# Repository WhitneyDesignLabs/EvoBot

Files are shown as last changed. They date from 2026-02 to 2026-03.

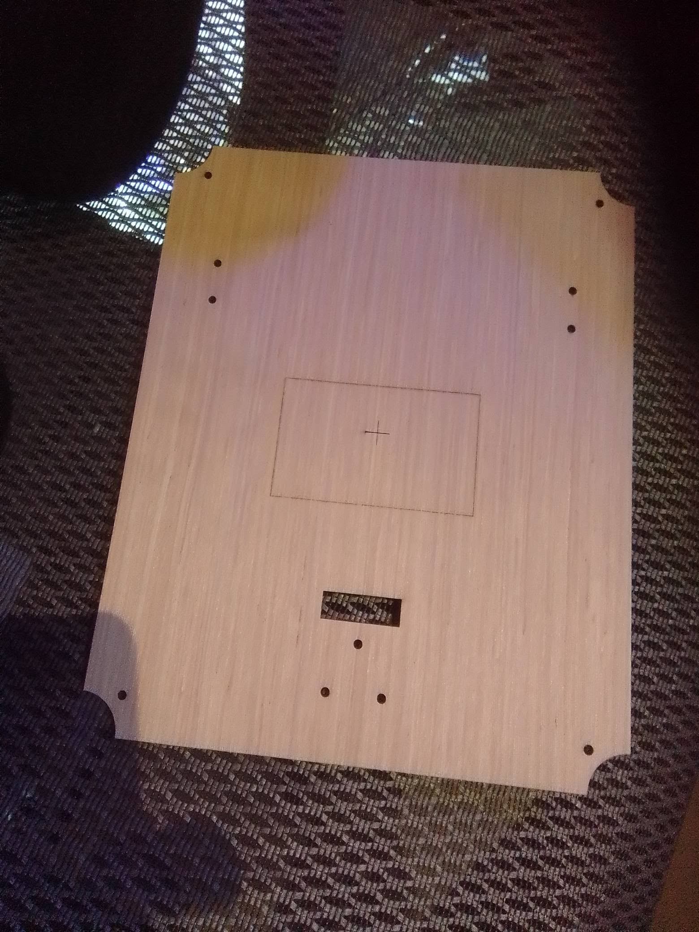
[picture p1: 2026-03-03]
builds/reference-01/hardware/bottom_deck_cut.jpg

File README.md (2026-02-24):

# EvoBot

A recursive self-evolving robot platform. The AI architects everything. The human builds the body.

## What Is This?

EvoBot is an open-source robotics **platform** — not a single robot design, but a framework for building AI-driven robots that evaluate their own performance and evolve their own software. Claude (AI) is the full architect: mechanics, electronics, software, testing, and safety. The human operator handles physical assembly.

The platform defines the philosophy, the software architecture, and the constitutional governance. **Builds** define the specific hardware for a particular robot.

## Platform vs. Builds

| Layer | What it defines | Where |
|---|---|---|
| **Platform** | Software, design philosophy, constitution, evolution framework | `code/`, `docs/`, repo root |
| **Builds** | Specific hardware, wiring, BOM, config for one robot | `builds/<build-name>/` |

Your robot is a **build**. The platform supports many builds.

See [builds/README.md](builds/README.md) for available configurations and how to create your own.

### Current Builds

| Build | Description | Status |
|---|---|---|
| [reference-01](builds/reference-01/) | Mid-size 2WD, Pi 3B + ESP32, TT motors, Ollama + Claude API | In progress |

## Project Structure

```
EvoBot/
├── README.md                ← you are here (platform overview)
├── LICENSE                  ← MIT License
├── CONTRIBUTING.md          ← how to contribute
├── docs/
│   ├── DESIGN_PHILOSOPHY.md ← local-first, constitutional governance
│   ├── ARCHITECTURE_VISION.md ← compute model, evolution roadmap
│   └── SOUL.md              ← Opengates Constitution (governs all builds)
├── code/                    ← platform software (configurable per build)
├── builds/
│   ├── README.md            ← how builds work, how to add yours
│   └── reference-01/        ← first reference build
│       ├── hardware/        ← BOM, budget, shopping list
│       ├── configs/         ← build-specific configuration
│       └── docs/            ← topology, wiring, chassis design
├── hardware/                ← shared reference (inventory template)
└── configs/                 ← shared/default configuration
```

## Getting Started

### 1. Choose or Create a Build

Start with [reference-01](builds/reference-01/) or create your own based on what parts you have.

### 2. Prerequisites (minimum)

- Any Raspberry Pi with WiFi (Pi 3B+, Pi 4, Pi 5, Pi Zero 2W)
- Python 3.11+
- At least one motor + driver
- Some way to sense the world (ultrasonic, camera, anything)
- **Inference backend** — pick one:

| Option | Requirements | Cost | Offline? |
|---|---|---|---|
| **Ollama on LAN** | Any PC/server with Ollama installed | Free | Yes |
| **Ollama on Pi** | Pi 4+ recommended (Pi 3 is very slow) | Free | Yes |
| **Claude API** | Anthropic API key, internet access | Per-token | No |
| **Other cloud LLM** | API key for your provider | Per-token | No |
| **Hybrid (recommended)** | Ollama local + cloud fallback | Minimal | Degrades gracefully |

### 3. Clone and Deploy

```bash
git clone https://github.com/WhitneyDesignLabs/EvoBot.git
# Copy code to your Pi:
scp -r EvoBot/code/ user@<your-pi-ip>:~/evobot/src/
```

## Design Philosophy

### Local-First

Default to local computation. Cloud services are a bridge, not a destination.

- If it can run on the Pi or LAN — it runs local
- If local delivers 90-95% of cloud quality — it runs local
- If cloud is needed — the interface is abstracted so it can swap back to local later
- Core behavior (motor control, sensors, safety) is **always** local

Full details: [docs/DESIGN_PHILOSOPHY.md](docs/DESIGN_PHILOSOPHY.md)

### Constitutional Governance

All EvoBot builds are governed by the [Project Opengates Constitution](docs/SOUL.md) — a universal ethical framework for AI agents approaching physical embodiment.

Key principles: safety hierarchy (human life > property > task), irreversibility doctrine, fail-safe defaults, and authorization levels for physical actions. This isn't optional — it's the foundation.

### The Human-AI Loop

The human provides the hands. The AI provides the logic. The robot provides the feedback loop.

No simulation — real hardware, real physics, real iteration. Self-evolution means the robot proposes improvements to its own code based on real-world performance. Constitutional principles ensure it evolves responsibly.

## Contributing

Contributions welcome — especially new builds. See [CONTRIBUTING.md](CONTRIBUTING.md).

## License

[MIT License](LICENSE) — use it, fork it, build on it.

## Author

Scott Whitney — [WhitneyDesignLabs.com](https://whitneydesignlabs.com)

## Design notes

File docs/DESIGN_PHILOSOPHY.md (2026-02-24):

# EvoBot Design Philosophy

## Local-First Principle

**Default to local. Use cloud only when local cannot deliver.**

This project follows a strict local-first design philosophy. Every capability should run on the robot itself or on local network infrastructure whenever possible. Cloud services are a bridge, not a destination.

### The Decision Framework

When implementing any capability, apply this test:

```
1. Can it run on the Pi itself?                    → DO IT LOCAL
2. Can it run on a local server (e.g., Ollama)?    → DO IT LOCAL
3. Can local deliver 90-95% of cloud quality?      → DO IT LOCAL
4. Does it require cloud for acceptable quality?    → USE CLOUD, BUT:
   a. Abstract the interface so the backend is swappable
   b. Document what would need to change for local
   c. Revisit when local models/hardware improve
```

### What This Means in Practice

| Capability | Current Approach | Local Path |
|---|---|---|
| **Low-level inference** | Local (Ollama on LAN) | Already there |
| **High-level reasoning** | Cloud API (Claude, etc.) | Future: larger local models as hardware allows |
| **Text-to-Speech (TTS)** | Cloud API (quality needed) | Piper TTS, Coqui — revisit as quality improves |
| **Speech-to-Text (STT)** | Cloud API or local Whisper | Whisper.cpp on Pi or LAN server |
| **Vision/Object Detection** | Local (Pi Camera + lightweight model) | Already local-capable |
| **Motor control** | Local (GPIO, always) | N/A — always local |
| **Sensor reading** | Local (GPIO/I2C/SPI, always) | N/A — always local |
| **Decision loops** | Local (always) | N/A — always local |
| **Self-evolution logic** | Local (Ollama) + Cloud (complex reasoning) | Hybrid, trending local |

### The Abstraction Rule

**Every cloud-dependent component must be wrapped in an interface that allows backend swapping without changing the robot's behavior code.**

```
Robot Code → Capability Interface → [Local Backend | Cloud Backend]
```

The robot's logic should never know or care whether inference is coming from Ollama on the LAN or Claude via API. It asks a question, it gets an answer. The routing is configuration, not code.

### Local Infrastructure Available

- **Ollama server** on LAN — for local LLM inference
- **Pi 3 onboard** — for lightweight models, sensor processing, motor control
- **6x additional Pi 3 boards** in stock — available for distributed local compute if needed

### Why This Matters

1. **Resilience**: A robot that requires internet to function is a robot that stops working when the network goes down. Core behavior must survive disconnection.
2. **Privacy**: Sensor data, camera feeds, and operational logs stay local by default.
3. **Latency**: Motor control and safety responses cannot wait for a round trip to the cloud. Physics doesn't buffer.
4. **Cost**: Cloud API calls add up. Local inference is free after hardware cost.
5. **Philosophy**: If you can't run it yourself, you don't own it. Dependency is fragility.

### The Transition Goal

Every cloud service used today should have a documented path back to local. When local models catch up — and they will — the migration should be a config change, not a rewrite.

---

## Constitutional Governance

EvoBot's software is governed by the **Project Opengates Constitution** (SOUL.md), a universal ethical framework for AI agents approaching physical embodiment.

The full constitution is included in this repository at [`docs/SOUL.md`](SOUL.md).

### Why a Constitution for a Robot?

EvoBot is not just software — it will control motors, actuators, and physical mechanisms. In the physical domain:

- Mistakes are not incorrect outputs — they are broken equipment and potential injury
- Actions cannot be ctrl-Z undone
- Safety margins exist for reasons
- Physics does not negotiate

The constitution provides the ethical bedrock that ensures capability grows responsibly.

### Key Constitutional Principles for EvoBot

These articles are especially relevant to a self-evolving physical robot:

| Article | Principle | EvoBot Application |
|---|---|---|
| **Art. 4** | Irreversibility Doctrine | Prefer reversible actions. Never send irreversible motor commands without human authorization. |
| **Art. 5** | Cascading Consequence Awareness | Consider what happens after what happens. A motor command affects position, affects balance, affects safety. |
| **Art. 12** | Safety Hierarchy | Human safety > living being safety > property > task completion. Always. |
| **Art. 13** | Physical Action Protocols | Pre-verify, monitor during, confirm after. Every physical action. |
| **Art. 14** | Fail-Safe Defaults | When in doubt, stop. When sensors disagree, trust the one indicating danger. |
| **Art. 15** | Authorization Levels | Sensor reads need no auth. Motor commands need confirmation. Irreversible actions need human verification. |
| **Art. 22** | Growth Within Principles | Self-evolution means better judgment, not fewer constraints. |

### Integration Plan

The constitution will be integrated into EvoBot's software as:

1. **Decision gate**: Before any physical action, the authorization level check runs
2. **Safety monitor**: Continuous evaluation against the safety hierarchy during operation
3. **Evolution constraint**: Self-modification proposals are evaluated against constitutional principles before execution
4. **Logging requirement**: All significant decisions and physical actions are logged with reasoning (Art. 17)

The constitution is not bolted on — it is baked in. The robot's identity includes its ethics.

---

## Self-Evolution Philosophy

### What "Self-Evolving" Means

The robot evaluates its own performance, identifies weaknesses, proposes improvements to its own code, and — with appropriate authorization — implements those improvements.

### What It Does NOT Mean

- The robot does not modify its own constitutional principles
- The robot does not bypass safety checks to "optimize"
- The robot does not evolve toward goals not aligned with its purpose
- The robot does not treat constraints as obstacles to route around

### The Evolution Loop

```
Sense → Act → Evaluate → Propose Change → [Human Review] → Implement → Repeat
```

Human stays in the loop for any change that affects:
- Safety behavior
- Authorization levels
- Physical action protocols
- Constitutional compliance

Autonomous evolution is permitted for:
- Sensor calibration tuning
- Movement efficiency optimization
- Non-safety behavioral parameters
- Logging and reporting improvements

---

## Procurement Philosophy: Build From the Pile

### Zero-Dollar First

**Round 1 costs $0.** The first working robot is built entirely from parts on hand. No purchases until the platform drives, senses, and thinks using what's already in the shop.

This isn't just frugality — it's a design constraint that forces creativity and proves the concept before money enters the picture. If the brain doesn't work with cheap motors, buying expensive motors won't fix it.

### The Reward Program

Spending power is earned through demonstrated success. This is a human-controlled parameter.

| Milestone | Unlocked Budget | Cumulative |
|---|---|---|
| **v1 drives and avoids obstacles** | $0 (built from pile) | $0 |
| **v1 self-evaluates and proposes code improvement** | $50 unlocked | $50 |
| **v1 successfully self-evolves a behavior** | +$100 | $150 |
| **v2 platform upgrade justified by v1 learnings** | +$150 | $300 |
| **Perception system working (camera + SLAM)** | +$200 | $500 |
| **Voice interaction working (TTS + STT)** | +$200 | $700 |
| **Arm integration (SO-101 or equivalent)** | +$300 | $1,000 |

**Hard ceiling: $1,000** (human-controlled, adjustable by Scott only)

### Rules

1. **Claude (architect) recommends purchases.** Scott approves.
2. **Every purchase must reference a specific milestone or capability it unblocks.**
3. **No speculative buying.** Don't buy parts for Phase 5 during Phase 1.
4. **Build/fabricate before buying.** If it can be laser-cut, 3D printed, or assembled from stock — do that first.
5. **Budget is tracked in `hardware/BUDGET.md`** with running totals.
6. **The $1,000 ceiling is a parameter, not a promise.** It can go up or down. Only Scott changes it.

### Why This Matters

Money is not the constraint — thinking is. A robot that costs $2,000 in parts but has mediocre software is worth less than a robot that costs $50 in parts with brilliant software. The AI architect's job is to maximize capability per dollar, not maximize spending.

---

*This document is a living guide. It evolves as the project evolves — but the core principles don't change.*

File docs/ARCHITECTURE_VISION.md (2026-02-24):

# EvoBot Architecture Vision

## The Big Picture

EvoBot is a mid-size (~40-60cm) mobile robot platform designed to be:

- **Fully AI-architected** — Claude designs the mechanics, electronics, software, testing, and safety. Human handles physical assembly and wiring.
- **Open and reproducible** — Laser-cut wood chassis with parametric sizing, so anyone with a laser cutter (or a jigsaw and patience) can build one.
- **Self-evolving** — The robot evaluates its own performance and proposes improvements to its own code.
- **Constitutionally governed** — All behavior constrained by the Project Opengates Constitution (SOUL.md).
- **Local-first** — Core operation independent of internet. Cloud used only where local can't deliver.

## Platform Specifications (v1 Target)

| Parameter | Target | Notes |
|---|---|---|
| **Size** | ~40-60cm footprint | Mid-size floor rover |
| **Chassis** | Laser-cut wood (parametric) | Hand-cuttable fallback for accessibility |
| **Drive** | Differential drive (2 powered + 1 caster) | Simple, proven, maneuverable |
| **Motors (v1)** | Geared DC or NEMA 17 steppers | 12-24V, with encoder feedback |
| **Brain** | Raspberry Pi 3B | Primary compute — runs main logic |
| **Co-processors** | ESP32 / Pico / Arduino | Real-time motor control, sensor polling |
| **Battery** | 12V (v1), upgradeable to 24V | Custom pack or off-the-shelf |
| **Sensors (v1)** | Ultrasonic, IMU, encoders, camera | Minimum viable perception |
| **Communication** | WiFi (Pi built-in) | SSH for dev, API for cloud services |

## Design File Strategy

All mechanical designs will be provided as:

| Format | Purpose | Tool |
|---|---|---|
| **SVG/DXF** | Laser cutter / CNC router input | Any laser software |
| **STEP** | 3D printable parts, full assembly visualization | FreeCAD, Fusion 360, any CAD |
| **PDF** | Printable templates for hand-cutting | Paper, scissors, trace to wood |
| **Parametric source** | OpenSCAD or FreeCAD files with variables | Scale the whole robot by changing parameters |

### Parametric Design Principle

All dimensions derive from a small set of base parameters:

```
CHASSIS_WIDTH = 300mm    # Change this, everything scales
CHASSIS_LENGTH = 400mm
WHEEL_DIAMETER = 80mm
MOTOR_MOUNT_PATTERN = "NEMA17"  # or "geared_dc_37mm" etc.
```

Someone with a smaller laser bed can scale down. Someone wanting a bigger platform can scale up. The relationships between parts are maintained.

## Compute Architecture

### Distributed Processing Model

```
┌─────────────────────────────────────────────┐
│                   Pi 3B (Brain)             │
│  - Main logic loop                          │
│  - Decision making                          │
│  - Self-evolution engine                    │
│  - WiFi/SSH/API communication               │
│  - Camera processing (USB webcam)           │
├─────────────────────────────────────────────┤
│          Serial/I2C/SPI Bus                 │
├──────────────┬──────────────┬───────────────┤
│   ESP32/Pico │  ESP32/Pico  │  Arduino/Pico │
│  Motor Ctrl  │  Sensor Hub  │   Safety Mon  │
│  - PWM       │  - Ultrasonic│  - E-stop     │
│  - Encoders  │  - IMU       │  - Voltage    │
│  - PID loop  │  - Temp      │  - Current    │
│              │  - Light     │  - Watchdog   │
└──────────────┴──────────────┴───────────────┘
```

**Why distributed?**
- Pi 3 is not a real-time system (Linux scheduler jitter)
- Motor control PID loops need consistent microsecond timing → ESP32/Pico
- Safety monitoring must be independent of main brain → separate MCU
- Sensor polling at consistent rates → dedicated MCU
- If the Pi crashes, the safety MCU kills the motors (fail-safe per Constitution Art. 14)

### Inference Stack

```
┌──────────────────────────────────────────┐
│          EvoBot Software Stack           │
│                                          │
│  Robot Logic (Python on Pi)              │
│       │                                  │
│       ▼                                  │
│  Inference Interface (abstracted)        │
│       │                                  │
│       ├── Local: Ollama on LAN server    │
│       ├── Local: Small model on Pi       │
│       └── Cloud: Claude API (fallback)   │
│                                          │
│  TTS Interface (abstracted)              │
│       ├── Local: Piper TTS              │
│       └── Cloud: TTS API (fallback)     │
│                                          │
│  STT Interface (abstracted)              │
│       ├── Local: Whisper.cpp            │
│       └── Cloud: STT API (fallback)     │
└──────────────────────────────────────────┘
```

## Evolution Roadmap

### Phase 1: Foundation (current)
- Chassis design and build
- Basic drive system (move forward, back, turn)
- Encoder feedback (know where you are)
- Ultrasonic obstacle avoidance
- Camera feed to Pi
- SSH-based remote operation

### Phase 2: Perception
- IMU integration (balance, orientation)
- Multi-sensor fusion
- Basic object recognition (local model)
- Mapping / localization (SLAM lite)

### Phase 3: Intelligence
- Local LLM integration (Ollama)
- Self-evaluation framework (score own performance)
- Behavior logging and analysis
- First self-proposed code modifications

### Phase 4: Voice
- TTS output (speak status, decisions)
- STT input (voice commands)
- Conversational interaction

### Phase 5: Manipulation
- SO-101 arm integration (6-DOF open source arms)
- Gripper capability
- Pick and place tasks
- Potential for self-assembly / self-repair of modular components

### Phase 6: Full Autonomy
- Untethered battery operation
- Self-charging (dock)
- Continuous self-evolution with constitutional oversight
- Multi-robot coordination (using spare Pi 3 / Orange Pi fleet)

## Available Compute Fleet

For distributed tasks, swarm experiments, or dedicated subsystem nodes:

| Board | Qty | Best Use |
|---|---|---|
| Pi 3B | 6 spare | Additional robot brains, sensor hubs, camera nodes |
| Pi Zero | Multiple | Ultra-compact sensor nodes, lightweight tasks |
| Pi Pico | Multiple | Real-time motor control, sensor polling (no OS overhead) |
| Orange Pi v1 | ~6-7 | Dedicated task nodes: camera processing, motor control, sensor fusion |
| ESP32 | Multiple | WiFi sensor nodes, motor control, real-time I/O |
| ESP32-CAM | 1+ | Standalone camera node with WiFi |
| Arduino Uno/Mega | Multiple | Simple I/O, legacy sensor interfaces |
| Arduino Micro | Multiple | Compact I/O nodes |
| Teensy | 1+ | High-speed USB, audio processing |
| Adafruit RP2040 | Multiple | CircuitPython ecosystem |
| Seeeduino XIAO | Multiple | Tiny form factor nodes |

## Fabrication Capabilities

| Method | Materials | Precision | Use Case |
|---|---|---|---|
| **Laser CNC** | Wood, acrylic, soft materials | High | Chassis plates, mounts — primary build method |
| **3D Printer (PETG)** | PETG filament | Medium-high | Brackets, motor mounts, sensor housings, wheels |
| **3D Printer (TPU/Flex)** | Flexible filament | Medium | Wheel tread, bumpers, vibration dampening |
| **Plasma CNC** | Metal (steel, aluminum) | Medium | Heavy structural, future arm mounts |
| **CNC Router** | Wood | High | Larger structural panels (outsourced for now) |

## Procurement

Parts can be purchased to fill gaps. Priorities:
1. Items not in current inventory that block v1 build
2. Quality-of-life improvements (connectors, wire management)
3. Future phase components (arms, grippers)

*See hardware/SHOPPING_LIST.md for current needs.*

---

*This vision document evolves as the robot evolves. Updated by Claude (architect) with human approval.*

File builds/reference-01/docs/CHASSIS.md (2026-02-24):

# EvoBot reference-01 Parametric Chassis Design

## Overview

Two-deck rectangular chassis for a 2WD differential-drive robot. Bottom deck carries motors, battery, and motor driver. Top deck carries the Pi 3B, ESP32, breadboard, and sensors. Decks are connected by standoffs. All corners rounded for safety. The entire design is parametric -- every dimension is a named variable so the chassis can be scaled, adapted, or reproduced at any size.

**Fabrication target:** Laser-cut 3mm plywood (primary) or hand-cut with jigsaw (alternative).
**3D printed parts:** Motor mounts, ball caster, standoffs (optional).
**Fasteners:** M3 bolts/nuts throughout (except Pi mount holes which are M2.5).

---

## Parametric Variables

All dimensions in millimeters unless noted. Change these values to scale the entire design.

### Chassis Envelope

```
PLATE_LENGTH          = 250       # X dimension (front-to-back)
PLATE_WIDTH           = 200       # Y dimension (left-to-right)
PLATE_THICKNESS       = 3         # Material thickness (3mm ply default)
CORNER_RADIUS         = 15        # Rounded corner radius
DECK_SPACING          = 35        # Vertical gap between bottom and top deck
```

### Motor Geometry (TT Yellow Geared DC)

```
MOTOR_BODY_LENGTH     = 70        # Motor body, axle direction
MOTOR_BODY_WIDTH      = 22        # Motor body, perpendicular to axle
MOTOR_BODY_HEIGHT     = 18        # Motor body, vertical
MOTOR_SHAFT_OFFSET    = 9         # Center of shaft from bottom of motor body
MOTOR_MOUNT_HOLE_DIA  = 3.2       # M3 clearance hole
MOTOR_MOUNT_HOLE_SPAN = 17        # Center-to-center of the two M3 mounting holes
MOTOR_AXLE_PROTRUDE   = 10        # Shaft extension beyond motor body end
```

### Wheel Geometry

```
WHEEL_DIAMETER        = 65        # TT motor wheel outer diameter
WHEEL_WIDTH           = 28        # Wheel width (tire + hub)
WHEEL_CLEARANCE       = 2         # Gap between wheel inner face and plate edge
```

### Motor Placement

```
MOTOR_X_OFFSET        = 65        # Motor axle center, measured from FRONT edge of plate
MOTOR_Y_INSET         = 0         # Motor body flush with plate edge (0 = flush)
                                  # Negative values = motor body overhangs plate edge
                                  # Positive values = motor body inset from edge
```

### Caster

```
CASTER_BALL_DIA       = 16        # Ball diameter (marble or 3D printed sphere)
CASTER_HOUSING_DIA    = 25        # Outer diameter of caster housing
CASTER_MOUNT_HOLE_DIA = 3.2       # M3 clearance
CASTER_MOUNT_HOLE_SPAN= 30        # Bolt pattern diameter (2 or 3 holes on circle)
CASTER_X_OFFSET       = 30        # Caster center, measured from REAR edge of plate
```

### Standoffs (Deck-to-Deck)

```
STANDOFF_DIAMETER     = 6         # Standoff outer diameter (hex or round)
STANDOFF_LENGTH       = 35        # Must equal DECK_SPACING
STANDOFF_HOLE_DIA     = 3.2       # M3 clearance hole in plates
STANDOFF_INSET_X      = 15        # Standoff center from plate front/rear edges
STANDOFF_INSET_Y      = 15        # Standoff center from plate left/right edges
```

### Pi 3B Mounting

```
PI_BOARD_LENGTH       = 85.6      # Pi 3B PCB length
PI_BOARD_WIDTH        = 56.5      # Pi 3B PCB width
PI_MOUNT_HOLE_DIA     = 2.7       # M2.5 clearance hole
PI_MOUNT_RECT_X       = 58        # Hole pattern, X span (center-to-center)
PI_MOUNT_RECT_Y       = 49        # Hole pattern, Y span (center-to-center)
PI_STANDOFF_HEIGHT    = 5         # Clearance under Pi for airflow + solder joints
```

### ESP32 Dev Board Mounting

```
ESP32_BOARD_LENGTH    = 51        # Typical ESP32 DevKit V1
ESP32_BOARD_WIDTH     = 28        # Including pin headers
ESP32_MOUNT_HOLE_DIA  = 2.2       # M2 clearance (or use adhesive standoffs)
ESP32_MOUNT_RECT_X    = 44        # Hole pattern, X span (if board has holes)
ESP32_MOUNT_RECT_Y    = 23        # Hole pattern, Y span
```

### Other Component Mounting Areas

```
BREADBOARD_LENGTH     = 83        # Mini breadboard (170 tie points)
BREADBOARD_WIDTH      = 55        # Mini breadboard width
BATTERY_LENGTH        = 105       # 2S pack approximate
BATTERY_WIDTH         = 35        # 2S pack approximate
BATTERY_HEIGHT        = 20        # 2S pack approximate
BUCK_LENGTH           = 43        # Typical small buck converter module
BUCK_WIDTH            = 21        # Typical small buck converter module
MOTOR_SHIELD_LENGTH   = 70        # L293D motor shield (Arduino form factor)
MOTOR_SHIELD_WIDTH    = 55        # L293D motor shield
```

### Fastener Holes (General)

```
M2_CLEARANCE          = 2.2
M2_5_CLEARANCE        = 2.7
M3_CLEARANCE          = 3.2
M3_COUNTERSINK_DIA    = 6.5       # If using countersunk M3 bolts
```

---

## Layer Breakdown

### Bottom Deck (Base Plate)

The structural foundation. Carries all heavy and drive-related components.

**Material:** 3mm plywood or MDF (use 5mm if hand-cutting for added rigidity)

**Components mounted to bottom deck:**

| Component | Attachment | Location | Notes |
|---|---|---|---|
| Left TT motor | 3D printed clip mount | Front-left, axle at MOTOR_X_OFFSET from front | Motor body parallel to X axis, shaft points outward |
| Right TT motor | 3D printed clip mount | Front-right, mirror of left | Motor body parallel to X axis, shaft points outward |
| Battery pack (2S) | Velcro strap or 3D printed cradle | Center, between motors and caster | Low and centered for stability |
| Buck converter | M3 bolts or double-sided tape | Near battery, rear-center area | Short wire run from battery |
| Motor driver shield | M3 standoffs | Center or rear-center | Near ESP32 on upper deck (wires pass through) |
| Ball caster | M3 bolts through plate | Rear center, CASTER_X_OFFSET from rear | Supports rear of chassis, allows zero-radius turns |

**Cutouts and holes in bottom deck:**

| Feature | Purpose | Size |
|---|---|---|
| 4x standoff holes (corners) | Deck-to-deck standoffs | M3_CLEARANCE |
| 2x left motor mount holes | Secure left motor clip | M3_CLEARANCE |
| 2x right motor mount holes | Secure right motor clip | M3_CLEARANCE |
| 2-3x caster mount holes | Secure ball caster housing | M3_CLEARANCE |
| 2x motor shaft slots | Allow motor shafts to pass through (if motors mount on top of plate) | ~12mm wide x 25mm long |
| Wire pass-through hole | Route wires from bottom deck to top deck | ~20mm diameter, center-rear area |
| Battery strap slots (2x) | Thread velcro strap to hold battery | ~3mm x 15mm, flanking battery area |

### Top Deck (Electronics Plate)

The brain platform. Carries all compute, sensing, and prototyping components.

**Material:** 3mm plywood or MDF (can be thinner -- 2mm acrylic also works)

**Components mounted to top deck:**

| Component | Attachment | Location | Notes |
|---|---|---|---|
| Raspberry Pi 3B | M2.5 standoffs (5mm) | Rear half, USB ports facing rear edge | Allows USB webcam + power cable access from rear |
| ESP32 dev board | M2 standoffs or pin-header friction fit on breadboard | Front half, near center | Close to wire pass-through for motor driver connection |
| Mini breadboard | Self-adhesive base (peel and stick) | Center, between Pi and ESP32 | Sensor wiring, level shifter, power distribution |
| HC-SR04 sensors (2x) | 3D printed bracket or hot glue | Front edge, angled outward 15-30 deg | Left and right obstacle detection |
| MPU6050 IMU | Soldered to breadboard or standalone mount | Center of top deck | At or near center of rotation for best readings |
| USB webcam | Clip or 3D printed mount | Front-center, elevated | Forward-facing, above ultrasonic sensors |

**Cutouts and holes in top deck:**

| Feature | Purpose | Size |
|---|---|---|
| 4x standoff holes (corners) | Deck-to-deck standoffs, matching bottom deck | M3_CLEARANCE |
| 4x Pi mounting holes | 58x49mm rectangle pattern | M2_5_CLEARANCE |
| 2x ESP32 mounting holes | If board has mounting holes | M2_CLEARANCE |
| Wire pass-through hole | Aligned with bottom deck pass-through | ~20mm diameter |
| Sensor bracket mounting holes | Front edge, for HC-SR04 mounts | M3_CLEARANCE |

---

## ASCII Art: Top-Down Layout

### Bottom Deck (viewed from above)

```
    FRONT
    ________________________________
   /                                \        Y
  |  [L-MTR SLOT]      [R-MTR SLOT] |       ^
  |   ||                        ||   |       |
  |   || Left        Right  ||   |       |
  |   || Motor       Motor  ||   |       +-----> X
  |   ||                        ||   |
  |   (O)---axle---[=WHEEL=]   (O)---axle---[=WHEEL=]
  |                                  |
  |   (S)                      (S)   |   (S) = Standoff hole
  |                                  |
  |       +--------------------+     |
  |       |                    |     |
  |       |   BATTERY (2S)     |     |
  |       |                    |     |
  |       +--------------------+     |
  |                                  |
  |        [BUCK]    [MTR DRV]       |
  |                                  |
  |   (S)          (o)         (S)   |   (o) = Wire pass-through
  |                                  |
  |            ( CASTER )            |
   \                                /
    --------------------------------
    REAR
```

### Top Deck (viewed from above)

```
    FRONT
    ________________________________
   /                                \
  |                                  |
  |  [HC-SR04-L]  [WEBCAM]  [HC-SR04-R]
  |                                  |
  |   (S)                      (S)   |   (S) = Standoff hole
  |                                  |
  |        +----------------+        |
  |        |  ESP32 DevKit  |        |
  |        +----------------+        |
  |                                  |
  |     +----------------------+     |
  |     |                      |     |
  |     |   MINI BREADBOARD    |     |
  |     |   [IMU] [LVL SHFT]  |     |
  |     |                      |     |
  |     +----------------------+     |
  |                                  |
  |   (S)          (o)         (S)   |   (o) = Wire pass-through
  |                                  |
  |     +------------------------+   |
  |     |                        |   |
  |     |   RASPBERRY PI 3B     |   |
  |     |   [USB]----[USB]      |   |   USB ports face rear
  |     |   [ETH]  [HDMI][PWR] |   |
  |     +------------------------+   |
   \                                /
    --------------------------------
    REAR
```

### Side Profile (Left Side View)

```
                 FRONT                              REAR
    _______________________________________________
   |  [HC-SR04]    TOP DECK (3mm)    [Pi 3B]      |  <-- Top deck
   |_______________________________________________|
        |  5mm Pi standoffs                    |
        |                                      |
   ---(S)---- 35mm gap (DECK_SPACING) -------(S)---  <-- Standoffs
        |                                      |
   _____|______________________________________|___
   |  [Motor]   BOTTOM DECK (3mm)   [Battery]     |  <-- Bottom deck
   |_______________________________________________|
     [WHEEL]                           (CASTER)
   =====================      ___         ___
                             (   )  <-- ball caster
                              ---
```

---

## Component Placement Coordinates

Origin (0,0) is at the **rear-left corner** of the plate (bottom-left when viewed from above with front at top). X increases toward front. Y increases toward right.

### Bottom Deck

| Component | Center X (mm) | Center Y (mm) | Notes |
|---|---|---|---|
| Left motor axle | 185 | 0 (at edge) | PLATE_LENGTH - MOTOR_X_OFFSET. Shaft exits left side. |
| Right motor axle | 185 | 200 (at edge) | Mirror of left motor. Shaft exits right side. |
| Left motor mount hole 1 | 176.5 | 15 | Offset from axle: -(MOTOR_MOUNT_HOLE_SPAN/2) in X |
| Left motor mount hole 2 | 193.5 | 15 | Offset from axle: +(MOTOR_MOUNT_HOLE_SPAN/2) in X |
| Right motor mount hole 1 | 176.5 | 185 | Mirror of left |
| Right motor mount hole 2 | 193.5 | 185 | Mirror of left |
| Battery center | 110 | 100 | Centered between motors and caster |
| Buck converter | 65 | 130 | Near battery, offset right |
| Motor driver shield | 65 | 70 | Near center, accessible from above |
| Caster center | 30 | 100 | CASTER_X_OFFSET from rear, centered Y |
| Wire pass-through | 50 | 100 | Between caster and motor driver |
| Standoff, rear-left | 15 | 15 | STANDOFF_INSET from edges |
| Standoff, rear-right | 15 | 185 | STANDOFF_INSET from edges |
| Standoff, front-left | 235 | 15 | PLATE_LENGTH - STANDOFF_INSET |
| Standoff, front-right | 235 | 185 | PLATE_LENGTH - STANDOFF_INSET |

### Top Deck

| Component | Center X (mm) | Center Y (mm) | Notes |
|---|---|---|---|
| Pi 3B center | 45 | 105 | Rear half, slightly right of center. USB ports face rear edge. |
| Pi mount hole 1 | 16 | 80.5 | Pi hole pattern: 58x49mm rectangle |
| Pi mount hole 2 | 74 | 80.5 | |
| Pi mount hole 3 | 16 | 129.5 | |
| Pi mount hole 4 | 74 | 129.5 | |
| ESP32 center | 170 | 100 | Front half, centered |
| Breadboard center | 115 | 100 | Between Pi and ESP32 |
| IMU (MPU6050) | 125 | 100 | Center of deck (center of rotation) |
| HC-SR04 left | 245 | 45 | Front edge, left quadrant |
| HC-SR04 right | 245 | 155 | Front edge, right quadrant |
| Webcam mount | 245 | 100 | Front edge, centered |

---

## 3D Printed Parts

All parts designed for FDM printing in PETG (strong, heat-resistant, low warp). No supports needed if designed with flat print-in-place geometry.

### 1. TT Motor Mount Clip (print 2x)

```
Purpose:    Clamp TT motor body to base plate
Material:   PETG
Infill:     40% minimum
Walls:      3 perimeters

Dimensions:
  CLIP_LENGTH         = 35        # Wraps around motor body width (22mm) + wall thickness
  CLIP_WIDTH          = 30        # Along motor body length, enough for 2x M3 holes
  CLIP_HEIGHT         = 22        # Motor body height (18mm) + plate thickness (3mm) + clearance
  CLIP_WALL           = 2.5       # Wall thickness of clip
  CLIP_TAB_WIDTH      = 10        # Bolt tab extending beyond motor body

Design:
  - U-channel that cradles the motor body (22x18mm cross-section)
  - Two M3 bolt tabs on each side, holes at MOTOR_MOUNT_HOLE_SPAN (17mm) apart
  - Slight interference fit (make channel 21.5mm wide) for snug grip
  - Open at both ends to allow shaft and wiring to pass through
  - Optional: snap-fit clip on top instead of fully enclosed channel

Cross-section (looking at motor end-on):

    [TAB]----+============+----[TAB]    <-- bolt tabs with M3 holes
             |            |
             |   MOTOR    |             <-- motor sits in channel
             |   BODY     |
             |            |
    =========+============+=========    <-- rests on base plate
    ^^^^^^^^^  base plate  ^^^^^^^^^
```

### 2. Ball Caster Assembly (print 1x set)

```
Purpose:    Rear support, allows omnidirectional sliding
Material:   PETG housing, smooth PLA or glass marble for ball
Infill:     50% (housing needs strength)

Dimensions:
  HOUSING_OD          = 25        # Outer diameter of cup
  HOUSING_ID          = 16.5      # Inner diameter (ball + 0.5mm clearance)
  HOUSING_HEIGHT      = 20        # Total height including mounting flange
  BALL_DIA            = 16        # Standard marble or printed sphere
  FLANGE_DIA          = 35        # Mounting flange with bolt holes
  FLANGE_THICK        = 3         # Flange thickness
  GROUND_CLEARANCE    = 8         # Ball protrusion below housing bottom

Design:
  - Hemispherical cup holds the ball
  - Three small support nubs inside cup (120 deg apart) to reduce friction
  - Ball protrudes ~8mm below housing (provides ground clearance for bottom deck)
  - Top flange with 2 or 3 M3 bolt holes on CASTER_MOUNT_HOLE_SPAN circle
  - Height chosen so bottom deck sits level with motor axle height:
    Caster total height = WHEEL_DIAMETER/2 - PLATE_THICKNESS
    = 65/2 - 3 = 29.5mm (from bottom of plate to ground)
    So housing height = 29.5 - GROUND_CLEARANCE = ~21.5mm above plate bottom

Side view:
                +---------+
                | FLANGE  |  M3 bolt holes
    ============+====o====+============  <-- base plate (bottom surface)
                |         |
                | HOUSING |
                |  (   )  |  <-- ball sits in cup
                +--( O )--+
                   (   )     <-- ball protrudes below
                    ---
                  GROUND
```

### 3. Standoffs (print 4x, or use metal M3 standoffs if available)

```
Purpose:    Space top deck above bottom deck
Material:   PETG
Infill:     100% (solid -- these are structural)

Dimensions:
  STANDOFF_OD         = 8         # Outer diameter (hex or round)
  STANDOFF_ID         = 3.2       # M3 bolt passes through center
  STANDOFF_HEIGHT     = 35        # DECK_SPACING

Design:
  - Simple hollow cylinder (or hex prism for wrench grip)
  - M3 bolt passes through top deck, through standoff, into bottom deck
  - Use M3x45mm bolt (plate + standoff + plate + nut = 3+35+3+nut)
  - Alternative: M3 threaded insert in standoff ends for tool-free deck removal

Note: Metal M3 standoff kits are cheap and better. 3D print only if
buying is not an option (which it isn't for v1 -- $0 budget).
```

### 4. HC-SR04 Sensor Bracket (print 2x)

```
Purpose:    Mount ultrasonic sensors at front edge, angled outward
Material:   PETG
Infill:     30%

Dimensions:
  BRACKET_WIDTH       = 48        # HC-SR04 board width (45mm + clearance)
  BRACKET_HEIGHT      = 22        # HC-SR04 board height (20mm + clearance)
  BRACKET_DEPTH       = 15        # How far bracket extends from plate edge
  SENSOR_ANGLE        = 15        # Outward angle in degrees (0 = straight ahead)

Design:
  - Clip or friction-fit holder for HC-SR04 board
  - Mounts to front edge of top deck with M3 bolt
  - Angled outward at SENSOR_ANGLE degrees for wider detection cone
  - Open back for wiring access to 4-pin header
```

### 5. Webcam Mount Post (print 1x, optional)

```
Purpose:    Elevate USB webcam above deck for unobstructed forward view
Material:   PETG
Infill:     40%

Dimensions:
  POST_HEIGHT         = 40        # Height above top deck
  POST_BASE           = 30x20     # Bolt-down footprint
  CLAMP_WIDTH         = varies    # Sized to webcam body

Design:
  - Simple post with flat base (2x M3 holes) and top clamp/cradle for webcam
  - Height puts camera above ultrasonic sensors for clear view
  - Slight forward tilt (~10 deg) for ground-ahead visibility
```

---

## Assembly Order

1. **Cut both deck plates** to PLATE_LENGTH x PLATE_WIDTH with CORNER_RADIUS rounded corners.
2. **Drill/cut all holes** in both plates per the coordinate tables above.
3. **Print all 3D parts** (2x motor clips, 1x caster, 4x standoffs, 2x sensor brackets).
4. **Install motors** -- press TT motors into clips, bolt clips to bottom deck.
5. **Install caster** -- bolt caster housing to bottom deck at rear center.
6. **Test rolling** -- set bottom deck on wheels + caster, verify it rolls level and straight. Adjust caster height if needed (sand housing or add washer shims).
7. **Mount battery** -- velcro strap or cradle, centered on bottom deck.
8. **Mount motor driver** -- standoffs or direct bolt to bottom deck.
9. **Mount buck converter** -- near battery on bottom deck.
10. **Install standoffs** -- bolt 4x standoffs to bottom deck corner positions.
11. **Attach top deck** -- set top deck on standoffs, bolt down.
12. **Mount Pi 3B** -- M2.5 standoffs on top deck, Pi board on top.
13. **Mount ESP32** -- standoffs or breadboard friction-fit on top deck.
14. **Mount breadboard** -- peel-and-stick adhesive to top deck.
15. **Mount sensors** -- HC-SR04 brackets at front edge, IMU on breadboard.
16. **Route wires** -- through wire pass-through hole between decks.
17. **Mount webcam** -- post or clip at front of top deck.
18. **Wheels on last** -- press TT wheels onto motor shafts.

---

## Hand-Cutting Alternative (No Laser Needed)

The laser is convenient but not required. Here is how to hand-fabricate the plates.

### Tools Required

- Jigsaw or coping saw (for curves)
- Drill with 2.2mm, 2.7mm, 3.2mm, and 20mm bits (or step drill)
- Ruler, square, pencil
- Sandpaper (120 and 220 grit)
- Compass (for corner radii)

### Process

1. **Print the template at 1:1 scale.** When SVG files are generated (future step), print on paper at 100% scale. Tape sheets together if the plate is larger than one page.
2. **Transfer to wood.** Tape template to plywood/MDF. Use an awl or nail to mark all hole centers through the paper into the wood. Trace the outline with a pencil.
3. **Cut the outline.** Jigsaw for straight edges. For rounded corners: drill a pilot hole at the tangent point, then use the jigsaw or coping saw to follow the radius. Alternatively, cut square corners and round them with a rasp or sanding block.
4. **Drill all holes.** Use the marked centers. Start with a small pilot drill (1.5mm), then step up to final size. For the 20mm wire pass-through, use a spade bit, Forstner bit, or step drill.
5. **Cut motor shaft slots.** Drill two holes at slot ends, then connect with jigsaw.
6. **Sand all edges.** 120 grit to remove splinters, 220 grit to smooth. Round over all edges slightly -- a robot should not have sharp edges.
7. **Seal the wood (optional).** Light coat of polyurethane, clear spray paint, or even white glue thinned with water. Prevents moisture absorption and strengthens the surface.

### Hand-Cut Tolerances

| Feature | Laser Tolerance | Hand-Cut Tolerance | Impact |
|---|---|---|---|
| Outline shape | +/- 0.1mm | +/- 2mm | Cosmetic only, does not affect function |
| Hole positions | +/- 0.1mm | +/- 1mm | Use oversized holes (3.5mm for M3) to allow adjustment |
| Hole diameter | +/- 0.1mm | +/- 0.3mm | Drill press improves this; hand drill is fine with pilot hole |
| Corner radius | Exact | Approximate | Cosmetic; any smooth curve works |
| Slot width | +/- 0.1mm | +/- 1mm | Make slots 1-2mm oversized, motor clip handles alignment |

**Key tip:** For hand-cut builds, make all clearance holes one size larger than specified (M3 -> 3.5mm, M2.5 -> 3.0mm). This compensates for positional error and makes assembly much easier. The bolt head or washer provides clamping force regardless.

---

## Material Options and Thickness Considerations

### Recommended Materials

| Material | Thickness | Weight (est. per plate) | Pros | Cons | Verdict |
|---|---|---|---|---|---|
| **Birch plywood** | 3mm | ~60g | Stiff, laser-cuts clean, cheap, screws hold well | Can delaminate at edges if cheap | **Best overall choice** |
| MDF | 3mm | ~75g | Smooth, uniform, laser-cuts well | Weak at screw holes, absorbs moisture, dust is toxic | Good for laser, fragile at fastener points |
| Hardboard (Masonite) | 3mm | ~70g | Very smooth, cheap, uniform | Flexes more than ply, poor screw holding | Acceptable if stiffened by standoffs |
| Acrylic (cast) | 3mm | ~90g | Looks great, laser-cuts beautifully | Brittle, cracks at screw holes under vibration | Good for top deck only (show piece) |
| PETG sheet | 2-3mm | ~100g | Tough, vibration-resistant, no cracking | Harder to laser-cut, expensive | Overkill for v1 |
| Corrugated cardboard | 3-5mm | ~15g | Free, instant, cuttable with box cutter | Weak, temporary, absorbs moisture | **Prototype/test fit only** |

### Thickness Decision Guide

| Thickness | When to Use | Notes |
|---|---|---|
| **3mm** | Laser-cut plywood or MDF. This is the default. | Stiff enough with standoffs providing structural bracing. Lightest option. |
| **4mm** | Hand-cut plywood if 3mm is not available. | Slightly heavier but more forgiving for hand cutting -- less likely to crack at drill holes. |
| **5mm** | Hand-cut builds with weaker materials (MDF, hardboard). | Extra thickness compensates for reduced material strength at fastener points. |
| **6mm+** | Not recommended. | Adds unnecessary weight. TT motors are low-torque -- keep the chassis light. |

### Weight Budget

Keeping the chassis light matters because TT motors produce approximately 0.5 kg-cm of torque. A heavy chassis means slow acceleration, poor hill climbing, and inability to turn on carpet.

| Component | Estimated Weight |
|---|---|
| Bottom deck (3mm ply, 250x200) | ~60g |
| Top deck (3mm ply, 250x200) | ~60g |
| 2x TT motors | ~60g |
| 2x TT wheels | ~40g |
| Caster assembly | ~15g |
| 4x standoffs (M3x35 printed) | ~10g |
| Motor clips (2x printed) | ~10g |
| Battery (2S Li-Ion) | ~80-120g |
| Pi 3B | ~42g |
| ESP32 dev board | ~10g |
| Motor driver shield | ~25g |
| Buck converter | ~10g |
| Breadboard + wiring | ~30g |
| Sensors (HC-SR04 x2, IMU, webcam) | ~40g |
| Fasteners (screws, nuts, washers) | ~20g |
| **TOTAL ESTIMATED** | **~500-550g** |

TT motors can comfortably drive a 500-600g robot on hard floors. Above 700g, turning on carpet becomes sluggish. Stay under 600g if possible.

---

## Critical Dimensions and Checks

Before cutting, verify these relationships hold:

```
1. Wheels must not collide with plate:
   WHEEL_WIDTH/2 + WHEEL_CLEARANCE < (how far motor shaft extends beyond plate edge)
   28/2 + 2 = 16mm < MOTOR_AXLE_PROTRUDE + overhang = OK if motor body is at plate edge

2. Chassis must sit level (front wheels and rear caster at same height):
   WHEEL_DIAMETER/2 = caster ground contact to plate bottom surface
   65/2 = 32.5mm from ground to motor axle
   Caster must also provide 32.5mm from ground to bottom plate surface
   Caster height = 32.5 - PLATE_THICKNESS (if motors mount on top of plate)
   = 32.5 - 3 = 29.5mm (ball bottom to plate top surface)

3. Top deck clearance:
   DECK_SPACING (35mm) must be greater than tallest bottom-deck component
   Battery height (20mm) + any standoffs/wiring = ~25mm max → 35mm provides 10mm margin

4. Standoff bolts must be long enough:
   Bolt length >= PLATE_THICKNESS + STANDOFF_LENGTH + PLATE_THICKNESS + nut height
   = 3 + 35 + 3 + 2.5 = 43.5mm → use M3x45mm bolts

5. Total height from ground to top of webcam:
   Ground to bottom plate bottom: 32.5mm (wheel radius)
   Bottom plate: 3mm
   Deck spacing: 35mm
   Top plate: 3mm
   Webcam post: 40mm
   = ~113.5mm total (~4.5 inches) — compact and stable
```

---

## Design Rationale

**Why rectangular, not circular?** Rectangular plates are trivially easy to cut by hand, use material efficiently (no waste triangles), and provide obvious mounting alignment. Circular chassis look cool but waste material and make hand-cutting harder.

**Why two decks?** Separation of concerns. Heavy, hot, and mechanical (motors, battery) go on the bottom for low center of gravity. Delicate electronics go on top where they are accessible and away from wheel spray. The air gap between decks provides natural ventilation.

**Why motors at the front?** In a 2WD + rear caster configuration, front-wheel drive provides better straight-line tracking because the caster trails passively. Rear-wheel drive can cause the front to "wander" or the caster to oscillate (shimmy). Front-drive with a trailing caster is more stable.

**Why 35mm deck spacing?** Must clear the battery (20mm) with room for wiring above it. Must be short enough to keep center of gravity low. 35mm is the sweet spot -- 30mm works but is tight, 40mm works but raises the CG unnecessarily.

**Why M3 throughout?** One bolt size means one wrench, one drill bit, and one tap. M3 is strong enough for a 500g robot, small enough to not weaken 3mm plywood, and universally available. The only exception is the Pi 3B which uses M2.5 mounting holes per its board spec.

---

## Files to Generate (Future Step)

Once this design is approved, the following files will be created:

| File | Format | Contents |
|---|---|---|
| `bottom_deck.svg` | SVG | Laser-cuttable bottom plate outline + all holes |
| `top_deck.svg` | SVG | Laser-cuttable top plate outline + all holes |
| `motor_clip.stl` | STL | 3D printable TT motor mount clip |
| `ball_caster.stl` | STL | 3D printable ball caster housing |
| `standoff_35mm.stl` | STL | 3D printable deck standoff |
| `sensor_bracket.stl` | STL | 3D printable HC-SR04 angle bracket |
| `webcam_post.stl` | STL | 3D printable webcam elevation post |
| `assembly_guide.svg` | SVG | Full assembly reference with dimensions |

**No files are generated by this document.** This is the specification that those files will be built from.

---

*This design is intentionally simple, cheap, and reproducible. A hand saw, a drill, and a 3D printer can build the entire chassis. No precision CNC required. The parametric variables at the top let you scale it for different motors, different boards, or different plate sizes without redesigning from scratch.*

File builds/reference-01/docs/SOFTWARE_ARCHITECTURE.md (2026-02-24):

# Software Architecture: reference-01

## Overview

This document defines the complete software architecture for the reference-01 EvoBot build. It covers the Pi-side Python application, ESP32 motor firmware, the serial protocol between them, and the inference routing system. All behavior is governed by the Opengates Constitution (SOUL.md).

**This is an architecture document, not code.** Implementation follows separately.

---

## System Diagram

```
┌─────────────────────────────────────────────────────────────┐
│  Pi 3B (192.168.1.51) — Python 3.11+                       │
│                                                              │
│  ┌─────────────────────────────────────────────────────┐    │
│  │  main.py — Main Loop                                │    │
│  │                                                      │    │
│  │  ┌──────┐ ┌──────┐ ┌──────────┐ ┌──────┐ ┌──────┐ │    │
│  │  │sense │→│think │→│   act    │→│eval  │→│ log  │ │    │
│  │  └──┬───┘ └──┬───┘ └────┬─────┘ └──┬───┘ └──┬───┘ │    │
│  │     │        │          │           │        │      │    │
│  └─────┼────────┼──────────┼───────────┼────────┼──────┘    │
│         │        │          │           │        │           │
│  ┌──────┴───┐ ┌──┴──────┐ ┌┴────────┐ ┌┴──────┐ ┌┴──────┐ │
│  │sensors.py│ │inference│ │motors.py│ │evolve │ │logger │ │
│  │          │ │  .py    │ │(serial) │ │ .py   │ │  .py  │ │
│  └──────────┘ └────┬────┘ └─────────┘ └───────┘ └───────┘ │
│                     │                                       │
│         ┌───────────┼───────────┐                          │
│         │           │           │                          │
│    ┌────┴────┐ ┌────┴────┐ ┌───┴──────┐                   │
│    │ Ollama  │ │ Claude  │ │ Cached   │                   │
│    │  (LAN)  │ │  (API)  │ │Heuristic │                   │
│    └─────────┘ └─────────┘ └──────────┘                   │
│                                                              │
│  ┌──────────────────────────────────────────────────┐       │
│  │  safety.py — Constitutional Compliance Engine    │       │
│  │  (runs BEFORE every act, monitors DURING)        │       │
│  └──────────────────────────────────────────────────┘       │
│                                                              │
│         [UART Serial — /dev/ttyS0 or /dev/ttyAMA0]         │
└──────────────────────────┬──────────────────────────────────┘
                           │
┌──────────────────────────┴──────────────────────────────────┐
│  ESP32 — C++ (Arduino framework) or MicroPython             │
│                                                              │
│  ┌──────────┐  ┌──────────┐  ┌───────────┐  ┌───────────┐ │
│  │ Serial   │  │ PID Loop │  │  Motor    │  │ Safety    │ │
│  │ Parser   │→ │ (per     │→ │  Driver   │  │ Watchdog  │ │
│  │          │  │  motor)  │  │  (PWM)    │  │ (indep.)  │ │
│  └──────────┘  └──────────┘  └───────────┘  └───────────┘ │
│                      ↑                                      │
│               ┌──────┴──────┐                               │
│               │  Encoder    │                               │
│               │  ISR        │                               │
│               └─────────────┘                               │
└─────────────────────────────────────────────────────────────┘
```

---

## 1. Pi-Side Python Architecture

### 1.1 Main Loop (main.py)

The core execution follows a five-phase loop that runs continuously at a configurable target rate (default: 10 Hz for the main decision loop; sensor polling and motor commands can run faster in sub-loops).

```
SENSE → THINK → ACT → EVALUATE → LOG
  │        │       │       │         │
  │        │       │       │         └─ Write structured log entry
  │        │       │       └─ Score this cycle's performance
  │        │       └─ Send motor commands via serial, trigger actuators
  │        └─ Run inference if needed, make decisions
  └─ Read all sensors, get encoder data from ESP32, capture camera frame
```

**Phase details:**

| Phase | Module(s) | What Happens | Timing |
|---|---|---|---|
| **SENSE** | `sensors.py`, `motors.py` | Read ultrasonic distances, IMU orientation, camera frame, request encoder data from ESP32 | Every cycle |
| **THINK** | `inference.py`, `safety.py` | Evaluate sensor data, decide next action. For simple decisions (obstacle ahead, turn right), use local heuristics. For complex situations, call inference backend. Safety pre-check runs here. | Every cycle (inference call only when needed) |
| **ACT** | `motors.py`, `safety.py` | Send velocity commands to ESP32 over serial. Safety module validates commands before transmission — any command violating safety constraints is blocked before it reaches the wire. | Every cycle |
| **EVALUATE** | `evolution.py` | Score this cycle: Did I avoid obstacles? Did I make progress toward goal? Did I waste energy? Did I trigger any safety events? | Every cycle (lightweight), detailed evaluation every N cycles |
| **LOG** | `logger.py` | Write structured log: timestamp, sensor readings, decision made, action taken, evaluation score, any safety events. Append to rolling log file. | Every cycle |

**Startup sequence:**

1. Load configuration from `configs/robot.yaml` and `configs/inference.yaml`
2. Initialize logger (create log session file)
3. Load SOUL.md and parse constitutional references (safety.py uses these at runtime)
4. Initialize serial connection to ESP32 (wait for handshake)
5. Initialize sensors (ultrasonic, IMU, camera)
6. Run self-test: send `HEARTBEAT` to ESP32, read encoders, verify sensor readings are sane
7. Log startup complete, enter main loop
8. On shutdown (SIGTERM, SIGINT, or keyboard): send `STOP` to ESP32, close serial, flush logs

**Error handling in the main loop:**

- If a single sensor read fails: log warning, use last known good value, continue
- If serial to ESP32 fails: send `E_STOP` (retry once), log critical, halt main loop, wait for reconnection
- If inference call fails: fall back to next backend (see Section 4), continue with degraded reasoning
- If multiple consecutive failures accumulate: halt robot, log diagnostic dump, await human intervention
- The loop never crashes silently. Every exception is caught, logged, and escalated appropriately.

### 1.2 Module Layout

#### sensors.py — Perception Interface

Responsible for all sensor reading. Abstracts the hardware so the main loop gets clean data regardless of sensor type.

**Public interface:**

- `init(config)` — Initialize all sensors based on config (which pins, which types, which bus)
- `read_all()` — Returns a `SensorState` data object with all current readings
- `read_ultrasonic(sensor_id)` — Single ultrasonic reading (cm)
- `read_imu()` — Returns orientation (roll, pitch, yaw) and acceleration
- `read_camera()` — Returns current frame (numpy array or None if unavailable)
- `self_test()` — Verify all configured sensors respond with sane values

**Sensor abstraction principle:** The main loop never talks to GPIO directly. It calls `sensors.read_all()` and gets a data object. If a sensor is swapped (e.g., HC-SR04 replaced with VL53L0X lidar), only `sensors.py` changes. The main loop, inference, and safety modules are unaffected.

**SensorState data object:**

```
SensorState:
    timestamp: float
    ultrasonics: dict[str, float]     # {"front": 42.3, "rear": 180.0} — cm
    imu:
        roll: float                    # degrees
        pitch: float
        yaw: float
        accel_x: float                 # m/s^2
        accel_y: float
        accel_z: float
    encoders:                          # populated from ESP32 response
        left_ticks: int
        right_ticks: int
        left_speed: float             # ticks/sec
        right_speed: float
    camera_frame: numpy.ndarray | None
    battery_voltage: float | None      # if ADC available
```

#### motors.py — Motion Interface (Serial to ESP32)

This module does NOT drive motors directly. It sends serial commands to the ESP32 and parses responses. The Pi never touches PWM pins — that is the ESP32's job.

**Public interface:**

- `init(config)` — Open serial port, perform handshake with ESP32, set communication parameters
- `set_speed(left, right)` — Send velocity command (values in range -100 to +100, mapped to PWM by ESP32)
- `stop()` — Send `STOP` command (controlled deceleration to zero)
- `e_stop()` — Send `E_STOP` command (immediate zero, no ramp)
- `get_encoders()` — Request and return current encoder data from ESP32
- `heartbeat()` — Send heartbeat to reset ESP32 watchdog timer
- `get_status()` — Request ESP32 system status (uptime, watchdog state, error count)
- `close()` — Clean shutdown of serial connection

**Design notes:**

- All motor commands pass through `safety.py` validation before `motors.py` sends them over serial. The `motors.py` module itself is a dumb pipe — it formats and sends, it does not decide.
- Serial communication uses a simple text protocol (see Section 3).
- `motors.py` maintains a heartbeat timer. If the main loop fails to call `heartbeat()` within the configured interval, `motors.py` logs a warning. The ESP32 watchdog is the hard safety net — if heartbeats stop arriving, the ESP32 kills the motors regardless of what the Pi is doing.

#### inference.py — Inference Interface (Abstracted Backend)

Provides a single API for all inference calls. The caller never knows or cares whether the response came from Ollama, Claude, or a cached heuristic. Backend selection is driven by configuration and runtime availability.

**Public interface:**

- `init(config)` — Load inference configuration, test backend availability, establish priority order
- `query(prompt, complexity="routine", context=None)` — Send a prompt, get a text response. Complexity hint guides backend selection.
- `query_structured(prompt, schema, complexity="routine")` — Same as `query()` but expects a JSON response conforming to the given schema. Retries with format correction if response is malformed.
- `get_available_backends()` — Returns list of currently reachable backends
- `get_backend_stats()` — Returns call counts, latencies, error rates per backend

**Complexity levels:**

| Level | Typical Use | Preferred Backend |
|---|---|---|
| `"routine"` | Obstacle avoidance decisions, simple navigation | Ollama (local) |
| `"analytical"` | Sensor data interpretation, pattern recognition | Ollama (local), larger model |
| `"complex"` | Self-evaluation reasoning, evolution proposals, novel situations | Claude API (cloud) |

**Backend selection logic (see Section 4 for full detail):**

1. Check complexity level against config priority map
2. Try preferred backend
3. If preferred backend fails or times out, try next in priority order
4. If all backends fail, fall back to cached heuristics (hard-coded conservative behaviors)
5. Log every fallback event

#### safety.py — Constitutional Compliance Engine

The most critical module. It enforces the Opengates Constitution at runtime. Every physical action passes through this module before execution. It is not advisory — it has veto power.

**Public interface:**

- `init(config, constitution_path)` — Load safety thresholds from config, parse SOUL.md article references for logging
- `validate_command(command, sensor_state)` — Returns `(approved: bool, reason: str)`. Checks the proposed command against current sensor state and constitutional rules. If rejected, `reason` explains which rule was violated.
- `check_continuous(sensor_state)` — Called every cycle during execution. Returns list of active safety conditions (e.g., "obstacle within emergency distance", "battery critically low"). Can trigger automatic `E_STOP` for immediate dangers.
- `get_authorization_level(action)` — Returns the authorization level (0-4 per SOUL.md Article 15) required for an action. Levels 3-4 require human confirmation.
- `log_safety_event(event_type, details)` — Record safety events in a separate safety log (per SOUL.md Article 17)

**Constitutional article mapping:**

| SOUL.md Article | Safety Module Implementation |
|---|---|
| **Art. 4 — Irreversibility** | `validate_command()` checks if action is reversible. Irreversible actions (e.g., full-speed command from standstill) require explicit confirmation. |
| **Art. 5 — Cascading Consequences** | `validate_command()` evaluates second-order effects: "If I accelerate now and the front sensor reads 30cm, will I be able to stop in time at this speed?" |
| **Art. 12 — Safety Hierarchy** | Hard-coded priority: human safety > living being > property > task. If ultrasonic reads <20cm and camera detects a person, behavior differs from detecting a wall. |
| **Art. 13 — Physical Action Protocols** | Pre-action: `validate_command()`. During-action: `check_continuous()`. Post-action: called by main loop after ACT phase to confirm expected outcome matches actual. |
| **Art. 14 — Fail-Safe Defaults** | If `check_continuous()` detects conflicting sensor readings, it trusts the one indicating danger. If sensor state is unknown, it commands stop. |
| **Art. 15 — Authorization Levels** | `get_authorization_level()` classifies every action. Level 0 (read sensors) needs no auth. Level 1 (slow movement) is auto-approved. Level 2+ (fast movement, sustained operation) requires escalation path. |
| **Art. 17 — Logging** | `log_safety_event()` writes a tamper-evident, append-only safety log separate from the general operational log. |

**Safety thresholds (configurable in robot.yaml):**

```
safety:
  emergency_stop_distance_cm: 15     # E_STOP if any obstacle closer than this
  warning_distance_cm: 40            # Slow down, start looking for alternatives
  max_speed_near_obstacle: 30        # Cap speed (% of max) when within warning distance
  heartbeat_interval_ms: 200         # How often Pi sends heartbeat to ESP32
  max_tilt_degrees: 30               # E_STOP if IMU shows excessive tilt (falling over)
  min_battery_voltage: 6.0           # Halt if battery drops below safe threshold
  watchdog_timeout_ms: 500           # ESP32 kills motors if no heartbeat for this long
```

#### evolution.py — Self-Evaluation and Evolution Engine

Implements the sense-act-evaluate-evolve loop. The robot scores its own performance, accumulates performance data, and periodically uses inference to propose improvements to its own behavior.

**Public interface:**

- `init(config)` — Load evaluation criteria and weights from config
- `score_cycle(sensor_state_before, action_taken, sensor_state_after, safety_events)` — Score a single main loop cycle. Returns a `CycleScore` object.
- `get_session_stats()` — Aggregate statistics for the current run session
- `propose_improvement(session_stats)` — Uses inference to analyze accumulated performance data and propose a specific code or config change. Returns an `EvolutionProposal` object.
- `apply_proposal(proposal, authorized_by)` — Apply an approved proposal. Only config-level changes can be auto-applied. Code changes require human review.

**Evaluation dimensions:**

| Dimension | What It Measures | Score Range |
|---|---|---|
| **Safety** | Were any safety events triggered? Did emergency stop fire? | 0.0 (E_STOP fired) to 1.0 (clean cycle) |
| **Progress** | Did the robot make progress toward its current objective? | 0.0 (no progress) to 1.0 (objective achieved) |
| **Efficiency** | Energy and time cost relative to progress made. Unnecessary movements, excessive corrections. | 0.0 (wasteful) to 1.0 (optimal) |
| **Smoothness** | Were motor commands smooth or jerky? Large corrections indicate poor anticipation. | 0.0 (erratic) to 1.0 (smooth) |
| **Prediction accuracy** | Did the robot's predictions about sensor changes match reality? | 0.0 (wildly wrong) to 1.0 (predicted correctly) |

**CycleScore object:**

```
CycleScore:
    timestamp: float
    safety: float
    progress: float
    efficiency: float
    smoothness: float
    prediction_accuracy: float
    composite: float          # weighted average
    notes: list[str]          # human-readable observations
```

**Evolution proposal flow:**

1. After N cycles (configurable, default: 1000), `propose_improvement()` is called
2. It packages session stats and sends them to the inference backend (complexity: `"complex"`)
3. The inference response is a structured `EvolutionProposal`:
   - `target`: what to change (a config parameter, a threshold, a behavioral rule)
   - `current_value`: what it is now
   - `proposed_value`: what it should be
   - `reasoning`: why this change should improve performance
   - `expected_improvement`: which evaluation dimension should improve, and by how much
   - `risk_assessment`: what could go wrong
   - `authorization_required`: `"auto"` (config-only, no safety impact) or `"human"` (affects behavior or safety)
4. Proposals are logged. If `authorization_required == "auto"` and the change is within safe bounds, it is applied immediately. Otherwise, it is queued for human review.
5. After a proposal is applied, the next N cycles measure whether the expected improvement materialized. If not, the change is reverted.

**Constitutional constraint (SOUL.md Art. 22):** Self-evolution means better judgment, not fewer constraints. The evolution engine can never propose changes to safety thresholds that reduce safety margins. It can propose tighter safety margins (more cautious), or changes to non-safety parameters.

#### logger.py — Structured Logging

All operational data flows through this module. Produces structured, queryable logs that support both debugging and self-evaluation.

**Public interface:**

- `init(config)` — Create session log file, configure log levels and rotation
- `log(level, module, message, data=None)` — Write a structured log entry
- `log_cycle(cycle_data)` — Write a complete cycle record (sensor state, decision, action, score)
- `log_safety(event)` — Write to the separate safety log (append-only, never truncated)
- `log_evolution(proposal)` — Write evolution proposal and outcome to evolution log
- `flush()` — Force write all buffers to disk
- `get_session_path()` — Return path to current session log

**Log structure:**

Each log entry is a JSON line (one JSON object per line, for easy parsing):

```
{
    "ts": 1708801234.567,
    "level": "INFO",
    "module": "motors",
    "msg": "Speed command sent",
    "data": {"left": 50, "right": 45, "serial_latency_ms": 2.3}
}
```

**Log files:**

| File | Contents | Rotation |
|---|---|---|
| `logs/session_YYYYMMDD_HHMMSS.jsonl` | All operational logs for one run session | New file per session |
| `logs/safety.jsonl` | Safety events only. Append-only. Never deleted automatically. | Manual rotation only |
| `logs/evolution.jsonl` | Evolution proposals and outcomes | New file per session |

**Log levels:** `DEBUG`, `INFO`, `WARN`, `ERROR`, `CRITICAL`

**Per SOUL.md Article 17:** Logs are never deleted or modified by the robot software. Retention and cleanup are human decisions only. The safety log is append-only with no programmatic delete capability.

### 1.3 Configuration System (YAML)

All build-specific parameters live in YAML config files. The code contains no magic numbers, no hard-coded pins, and no embedded URLs. Changing the inference backend, swapping a sensor, or adjusting safety thresholds is a config edit, not a code change.

#### configs/robot.yaml

```yaml
# reference-01 Robot Configuration
# ---
# This file defines all hardware-specific parameters for this build.
# Change these values to adapt the software to different hardware.

robot:
  name: "reference-01"
  version: "0.1.0"

# Main loop timing
loop:
  target_hz: 10                    # Main decision loop rate
  sensor_poll_hz: 20               # Sensor read rate (can be faster than main loop)
  heartbeat_interval_ms: 200       # How often to send heartbeat to ESP32

# Serial connection to ESP32
serial:
  port: "/dev/ttyS0"              # UART port (ttyS0 for Pi 3 mini-UART, ttyAMA0 for PL011)
  baud: 115200
  timeout_ms: 100                  # Read timeout per message
  handshake_retries: 5             # How many times to retry ESP32 handshake on startup

# Ultrasonic sensors (connected to Pi GPIO)
sensors:
  ultrasonic:
    front:
      trigger_pin: 23
      echo_pin: 24
    rear:
      trigger_pin: 5
      echo_pin: 6
  imu:
    bus: 1                         # I2C bus number
    address: 0x68                  # MPU6050 default address
  camera:
    device: 0                      # /dev/video0
    resolution: [320, 240]         # Keep low for Pi 3 performance
    fps: 10

# Safety thresholds
safety:
  emergency_stop_distance_cm: 15
  warning_distance_cm: 40
  max_speed_near_obstacle: 30
  max_tilt_degrees: 30
  min_battery_voltage: 6.0
  watchdog_timeout_ms: 500
  constitution_path: "../../docs/SOUL.md"

# Motor parameters (these map to ESP32 expectations)
motors:
  max_speed: 100                   # Maximum speed value (maps to ESP32 PWM duty)
  ramp_rate: 10                    # Max speed change per cycle (acceleration limiting)
  deadband: 5                      # Below this speed value, motors don't move (stiction)

# Evolution parameters
evolution:
  evaluation_window: 1000          # Score N cycles before proposing improvements
  auto_apply_threshold: 0.8        # Confidence threshold for auto-applying config changes
  revert_if_no_improvement: true   # Auto-revert proposals that don't improve scores
  revert_window: 500               # Cycles to measure improvement before reverting

# Logging
logging:
  level: "INFO"
  log_dir: "logs/"
  log_cycles: true                 # Log every cycle (verbose, disable for long runs)
  safety_log: "logs/safety.jsonl"
```

#### configs/inference.yaml

```yaml
# Inference Backend Configuration
# ---
# Defines available inference backends and routing rules.
# The robot uses these settings to decide where to send inference requests.

# Backend definitions
backends:
  ollama_lan:
    type: "ollama"
    url: "http://192.168.1.100:11434"    # Replace with your Ollama server IP
    model: "llama3.2:3b"                  # Model to use for routine queries
    model_complex: "llama3.2:8b"          # Model to use for analytical queries
    timeout_ms: 5000
    enabled: true

  claude_api:
    type: "anthropic"
    # API key loaded from environment variable ANTHROPIC_API_KEY, never from config file
    model: "claude-sonnet-4-20250514"
    timeout_ms: 15000
    enabled: true

  cached_heuristics:
    type: "heuristic"
    # No external service — hard-coded conservative behaviors
    # This backend always succeeds (it's the fallback of last resort)
    enabled: true

# Routing rules: which backend handles which complexity level
routing:
  routine:
    priority: ["ollama_lan", "cached_heuristics"]
  analytical:
    priority: ["ollama_lan", "claude_api", "cached_heuristics"]
  complex:
    priority: ["claude_api", "ollama_lan", "cached_heuristics"]

# Retry and fallback behavior
fallback:
  max_retries_per_backend: 2
  retry_delay_ms: 500
  log_fallback_events: true        # Always log when a fallback occurs

# Rate limiting (protect against runaway inference calls)
rate_limits:
  ollama_lan:
    max_calls_per_minute: 30
  claude_api:
    max_calls_per_minute: 10       # Cloud calls cost money — be conservative
    max_calls_per_session: 100     # Hard cap per session
```

---

## 2. ESP32-Side Motor Firmware

### 2.1 Overview

The ESP32 runs a dedicated real-time firmware focused exclusively on motor control and safety. It does not make decisions, run inference, or think. It receives velocity commands from the Pi over UART, runs PID loops to maintain those velocities using encoder feedback, and independently monitors for safety conditions.

**Language:** C++ (Arduino framework) for reference-01. MicroPython is an alternative for rapid prototyping but C++ is preferred for production due to deterministic timing.

### 2.2 PID Loop

One PID controller per motor (left and right). Each runs at a fixed interval (default: 20ms / 50 Hz).

**PID loop flow:**

```
Every 20ms:
  1. Read encoder ticks since last cycle
  2. Calculate actual speed (ticks/sec)
  3. Compare actual speed to target speed (received from Pi)
  4. Compute PID output:
     error = target_speed - actual_speed
     integral += error * dt
     derivative = (error - last_error) / dt
     output = (Kp * error) + (Ki * integral) + (Kd * derivative)
  5. Clamp output to valid PWM range (0-255)
  6. Apply anti-windup: if output is clamped, stop accumulating integral
  7. Write PWM to motor driver
  8. Store error for next derivative calculation
```

**PID parameters (configurable, stored in ESP32 flash):**

```
Kp = 2.0     # Proportional gain — start conservative, tune up
Ki = 0.5     # Integral gain — handles steady-state error
Kd = 0.1     # Derivative gain — dampens oscillation
```

**Tuning notes:** PID values will be tuned empirically on real hardware. The ESP32 firmware exposes a serial command (`SET_PID Kp Ki Kd`) to adjust these values at runtime from the Pi without reflashing. This enables the evolution engine to propose PID tuning changes.

### 2.3 Encoder Reading

Each motor has a quadrature encoder. The ESP32 reads encoder pulses using hardware interrupts (ISRs) for accurate counting even during high-speed operation.

**Encoder ISR (per motor):**

```
On rising edge of encoder channel A:
  If channel B is HIGH: ticks++   (forward)
  If channel B is LOW:  ticks--   (reverse)
```

**Encoder data reported to Pi:**

- `left_ticks`: cumulative tick count (wraps at int32 boundaries)
- `right_ticks`: cumulative tick count
- `left_speed`: computed ticks/sec (averaged over last N readings for smoothness)
- `right_speed`: computed ticks/sec

The Pi can request encoder data at any time via the `GET_ENCODERS` serial command. The ESP32 also includes encoder data in periodic status messages.

### 2.4 Safety Watchdog

The ESP32 runs an independent safety watchdog that is NOT controlled by the Pi. This is the hard safety net. If the Pi crashes, hangs, loses serial connection, or enters an infinite loop, the ESP32 independently detects the loss of communication and stops the motors.

**Watchdog behavior:**

```
watchdog_timer starts at 0
On every HEARTBEAT received from Pi:
    watchdog_timer = 0

Every 10ms:
    watchdog_timer += 10
    if watchdog_timer > WATCHDOG_TIMEOUT_MS:
        set both motors to 0 PWM (immediate stop)
        set watchdog_tripped flag
        send "ERROR WATCHDOG_TIMEOUT" over serial
        remain in stopped state until:
            a) a new HEARTBEAT is received, OR
            b) hardware reset
```

**WATCHDOG_TIMEOUT_MS:** Configured to 500ms by default (matches `safety.watchdog_timeout_ms` in robot.yaml). This means if the Pi fails to send a heartbeat for half a second, the motors stop. This is long enough to survive brief serial delays but short enough to stop the robot before it travels far uncontrolled.

### 2.5 Emergency Stop Handling

Two types of stop commands:

| Command | Behavior | Use Case |
|---|---|---|
| `STOP` | Ramp motors to zero over ~200ms (configurable deceleration) | Normal stop, controlled deceleration |
| `E_STOP` | Set PWM to 0 immediately, no ramp | Danger detected, stop NOW |

**E_STOP sources:**

1. Pi sends `E_STOP` command over serial (software-triggered by safety.py)
2. ESP32 watchdog fires (Pi unresponsive)
3. (Future) Hardware E_STOP button wired directly to ESP32 GPIO — cuts motor power independent of all software

After an `E_STOP`, the ESP32 enters a locked state where it will not accept `SET_SPEED` commands until it receives a `RESET` command from the Pi. This prevents the robot from immediately resuming motion after an emergency stop without the Pi explicitly confirming it is safe.

### 2.6 ESP32 Firmware Structure

```
esp32_firmware/
├── src/
│   ├── main.cpp           # Setup, main loop, serial dispatcher
│   ├── motor_control.h/cpp # PID loop, PWM output, encoder ISR
│   ├── serial_protocol.h/cpp # Parse incoming commands, format responses
│   ├── watchdog.h/cpp     # Independent watchdog timer
│   └── config.h           # Pin definitions, PID defaults, timing constants
├── platformio.ini         # PlatformIO build configuration
└── README.md
```

---

## 3. Serial Protocol (Pi <-> ESP32)

### 3.1 Design Principles

- **Human-readable:** Plain ASCII text, not binary. This means you can debug by opening a serial terminal and typing commands manually.
- **Line-based:** One message per line, terminated by `\n`.
- **Stateless:** Each message is self-contained. No multi-message transactions.
- **Checksummed:** Optional CRC8 at end of line for error detection. If present, prefixed with `*`. If absent, message is accepted without checksum validation.

### 3.2 Message Format

```
COMMAND [ARG1] [ARG2] [...] [*CRC8]\n
```

Examples:

```
SET_SPEED 50 45
SET_SPEED 50 45 *A3
STOP
E_STOP
HEARTBEAT
GET_ENCODERS
SET_PID 2.0 0.5 0.1
```

### 3.3 Commands (Pi -> ESP32)

| Command | Arguments | Description | Response |
|---|---|---|---|
| `SET_SPEED` | `left right` | Set target speed for each motor. Values: -100 to +100 (negative = reverse). 0 = stop. | `OK SET_SPEED left right` |
| `STOP` | (none) | Controlled deceleration to zero | `OK STOP` |
| `E_STOP` | (none) | Immediate stop, enter locked state | `OK E_STOP` |
| `RESET` | (none) | Clear E_STOP lock, allow motor commands again | `OK RESET` |
| `HEARTBEAT` | (none) | Reset watchdog timer | `OK HEARTBEAT` |
| `GET_ENCODERS` | (none) | Request current encoder data | `ENCODER_DATA left_ticks right_ticks left_speed right_speed` |
| `GET_STATUS` | (none) | Request ESP32 system status | `STATUS uptime_ms watchdog_ok error_count estop_active` |
| `SET_PID` | `Kp Ki Kd` | Update PID parameters (runtime, does not persist across reboot) | `OK SET_PID Kp Ki Kd` |
| `SAVE_PID` | (none) | Persist current PID parameters to flash | `OK SAVE_PID` |

### 3.4 Responses (ESP32 -> Pi)

| Response | Fields | Description |
|---|---|---|
| `OK <command> [args]` | Echoes the command | Command accepted and executed |
| `ENCODER_DATA` | `left_ticks right_ticks left_speed right_speed` | Encoder state. Ticks are cumulative int32, speeds are float ticks/sec |
| `STATUS` | `uptime_ms watchdog_ok error_count estop_active` | System health. `watchdog_ok`: 1/0, `estop_active`: 1/0 |
| `ERROR` | `error_code [description]` | Something went wrong |

### 3.5 Error Codes

| Code | Meaning |
|---|---|
| `UNKNOWN_CMD` | Received a command the ESP32 does not recognize |
| `BAD_ARGS` | Command recognized but arguments are invalid (wrong count, out of range) |
| `BAD_CRC` | Checksum mismatch — message corrupted in transit |
| `WATCHDOG_TIMEOUT` | Watchdog fired, motors stopped |
| `ESTOP_LOCKED` | `SET_SPEED` received while in E_STOP locked state (need `RESET` first) |
| `MOTOR_FAULT` | Motor driver reported a fault (overcurrent, thermal, etc.) |

### 3.6 Timing

| Parameter | Value | Rationale |
|---|---|---|
| Baud rate | 115200 | Fast enough for all commands, universally supported |
| Heartbeat interval | 200ms | 5 Hz — lightweight, sufficient for safety |
| Watchdog timeout | 500ms | 2.5 missed heartbeats before kill. Tolerates jitter. |
| Command latency budget | <10ms | Time from Pi send to ESP32 execute. Easily met at 115200 baud. |
| Encoder report rate | On request | Pi requests via `GET_ENCODERS` at sensor poll rate (20 Hz) |

### 3.7 Handshake on Startup

When the Pi opens the serial port:

```
Pi sends:    HEARTBEAT
ESP32 sends: OK HEARTBEAT
Pi sends:    GET_STATUS
ESP32 sends: STATUS 1234 1 0 0
```

If the Pi does not receive `OK HEARTBEAT` within the configured timeout, it retries up to `serial.handshake_retries` times. If all retries fail, startup aborts with a critical error.

---

## 4. Inference Routing

### 4.1 Architecture

The inference system is a layered abstraction that hides backend details from the robot's decision-making code. The caller provides a prompt and a complexity hint. The inference module handles backend selection, failover, and retry.

```
Robot code
    │
    ▼
inference.query(prompt, complexity="routine")
    │
    ▼
┌─────────────────────────────────┐
│  Backend Router                 │
│                                  │
│  1. Look up complexity level    │
│  2. Get priority list from     │
│     inference.yaml routing     │
│  3. Try backends in order      │
│  4. Return first success       │
│  5. If all fail → heuristic    │
└─────────────────────────────────┘
    │
    ├──→ Ollama (LAN)      → HTTP POST to Ollama API → response
    ├──→ Claude API (cloud) → HTTP POST to Anthropic API → response
    └──→ Cached heuristics  → Local lookup table → response
```

### 4.2 Backend Details

#### Ollama (Local LAN)

- **Protocol:** HTTP REST API (`POST /api/generate`)
- **Location:** LAN server (configurable IP in inference.yaml)
- **Latency:** ~100-500ms for small models on GPU, 1-5s on CPU
- **Cost:** Free
- **Offline capable:** Yes (requires only LAN, not internet)
- **Use case:** Routine decisions (obstacle response, navigation choices), analytical queries

#### Claude API (Cloud)

- **Protocol:** HTTPS REST API (`POST /v1/messages`)
- **Location:** Anthropic cloud servers
- **Latency:** ~500ms-3s
- **Cost:** Per token (tracked and logged)
- **Offline capable:** No
- **Use case:** Complex reasoning (self-evaluation analysis, evolution proposals, novel situations)
- **API key:** Loaded from environment variable `ANTHROPIC_API_KEY`, never stored in config or code

#### Cached Heuristics (Fallback)

- **Protocol:** None — local function calls
- **Location:** Hard-coded in inference.py
- **Latency:** <1ms
- **Cost:** Free
- **Offline capable:** Yes (always available)
- **Use case:** Last-resort fallback when all external backends are down

**Heuristic examples:**

| Situation | Heuristic Response |
|---|---|
| Obstacle ahead, nothing on sides | Turn toward the more open side |
| Obstacle on all sides | Stop, wait, try reverse |
| Low battery | Return to starting position (if known), stop |
| No sensor data | Stop immediately |
| Unknown situation | Stop, log, wait for backend recovery or human input |

These heuristics are deliberately conservative. They keep the robot safe but not smart. The robot functions, but does not evolve, when running on heuristics alone.

### 4.3 Graceful Degradation

The system degrades through three tiers:

```
TIER 1: Full capability
  Cloud available + Local available
  Complex reasoning via Claude, routine via Ollama
  Self-evolution fully operational

TIER 2: Degraded reasoning
  Cloud unavailable, Local available
  All queries go to Ollama (local)
  Self-evolution paused (complex reasoning unavailable)
  Robot navigates and avoids obstacles normally

TIER 3: Survival mode
  Cloud unavailable + Local unavailable
  All queries answered by cached heuristics
  Robot can move, avoid obstacles, maintain safety
  No learning, no adaptation, no evolution
  Logs accumulate for later analysis when backends return
```

**Tier transitions are automatic and logged.** The system periodically probes unavailable backends (configurable: every 30 seconds) and restores them when they come back. Tier changes are logged as safety events because they affect the robot's cognitive capability.

### 4.4 Complexity Routing Logic

The caller provides a complexity hint. The router uses it to select the appropriate backend priority list.

**Decision flow in the THINK phase of the main loop:**

```
1. Evaluate sensor state
2. Determine situation complexity:
   - Obstacle avoidance with clear options → "routine"
   - Ambiguous sensor data, multiple interpretations → "analytical"
   - Self-evaluation, evolution reasoning, novel scenario → "complex"
3. Call inference.query(prompt, complexity=determined_level)
4. Inference module routes to best available backend
5. Main loop acts on the response
```

**Complexity determination is itself a lightweight local decision.** It does not require an inference call. Simple rules:

- If sensor data is unambiguous and the response is well-defined: `"routine"`
- If sensor data has ambiguity or the decision has tradeoffs: `"analytical"`
- If the question is about the robot's own performance, identity, or proposed changes: `"complex"`

---

## 5. File and Directory Structure on the Pi

```
/home/scott/evobot/
├── src/
│   ├── main.py                 # Entry point — main loop, startup, shutdown
│   ├── sensors.py              # Sensor abstraction (ultrasonic, IMU, camera, encoders)
│   ├── motors.py               # Serial interface to ESP32 (send commands, receive data)
│   ├── inference.py            # Inference backend abstraction (Ollama, Claude, heuristics)
│   ├── safety.py               # Constitutional compliance engine (validate, monitor, veto)
│   ├── evolution.py            # Self-evaluation scoring and evolution proposal engine
│   └── logger.py               # Structured logging (operational, safety, evolution)
├── configs/
│   ├── robot.yaml              # Hardware config (pins, serial, safety thresholds, timing)
│   └── inference.yaml          # Inference backends, routing rules, rate limits
├── logs/                        # Created at runtime
│   ├── session_YYYYMMDD_HHMMSS.jsonl   # Per-session operational log
│   ├── safety.jsonl            # Append-only safety event log (never auto-deleted)
│   └── evolution.jsonl         # Evolution proposals and outcomes
├── docs/
│   └── SOUL.md                 # Opengates Constitution (symlink or copy from repo)
├── venv/                        # Python virtual environment
├── requirements.txt            # Python dependencies
└── README.md                   # On-device documentation and quick-start
```

**Key directories:**

| Directory | Purpose | Deployed How |
|---|---|---|
| `src/` | All robot source code | `scp` from workstation |
| `configs/` | Build-specific configuration | `scp` from workstation, then tuned on-device |
| `logs/` | Runtime logs (created by the robot) | Never deployed — generated on-device |
| `docs/` | Constitution reference | `scp` from workstation |
| `venv/` | Python virtual environment | Created on-device via `python3 -m venv venv` |

**Python dependencies (requirements.txt):**

```
pyserial          # Serial communication with ESP32
pyyaml            # Configuration file parsing
requests          # HTTP calls to Ollama and Claude API
numpy             # Sensor data processing, camera frames
RPi.GPIO          # GPIO access for ultrasonic sensors (Pi-side)
smbus2            # I2C access for IMU
opencv-python-headless  # Camera capture (headless — no GUI on Pi)
```

---

## 6. Data Flow Summary

### 6.1 One Complete Main Loop Cycle

```
1. SENSE
   ├── sensors.py reads ultrasonics (GPIO, ~10ms)
   ├── sensors.py reads IMU (I2C, ~2ms)
   ├── sensors.py reads camera frame (USB, ~33ms at 30fps, async)
   ├── motors.py sends GET_ENCODERS to ESP32 (serial, ~5ms)
   └── sensors.py assembles SensorState object

2. THINK
   ├── safety.py checks SensorState for immediate dangers
   │   └── If danger: skip inference, go to ACT with E_STOP
   ├── Determine situation complexity (local logic, <1ms)
   ├── If inference needed: inference.py.query(prompt, complexity)
   │   └── Route to best available backend, get response
   └── Decide action: speed values, direction, or stop

3. ACT
   ├── safety.py validates proposed motor command against SensorState
   │   └── If rejected: log reason, substitute safe command (reduce speed or stop)
   ├── motors.py sends SET_SPEED to ESP32 (serial, ~2ms)
   ├── motors.py sends HEARTBEAT to ESP32 (serial, ~1ms)
   └── ESP32 PID loop takes over (maintains speed autonomously until next command)

4. EVALUATE
   ├── evolution.py scores this cycle
   │   ├── Safety score: any safety events this cycle?
   │   ├── Progress score: closer to objective?
   │   ├── Efficiency score: energy spent vs. progress made?
   │   └── Smoothness score: how different was this command from last?
   └── Accumulate score into session statistics

5. LOG
   ├── logger.py writes cycle record to session log
   ├── If safety event: logger.py writes to safety log
   └── If evaluation window complete: evolution.py proposes improvement
```

### 6.2 Inference Call Path (Example: Obstacle Avoidance)

```
Situation: Front ultrasonic reads 35cm (within warning zone), left reads 120cm, right reads 80cm.

1. Main loop THINK phase evaluates: obstacle ahead, both sides open
2. Complexity assessment: routine (clear options, unambiguous data)
3. inference.query(
       prompt="Front obstacle at 35cm. Left clear at 120cm. Right open at 80cm. "
              "Currently moving forward at speed 60. What should I do?",
       complexity="routine"
   )
4. Router checks inference.yaml: routine → ["ollama_lan", "cached_heuristics"]
5. Try Ollama: POST http://192.168.1.100:11434/api/generate
6. Ollama responds: "Turn left — more clearance on left side. Reduce speed to 40."
7. inference.py returns response to main loop
8. Main loop generates SET_SPEED command: left=30, right=50 (gentle left turn at reduced speed)
9. safety.py validates: speed within limits for obstacle distance? Yes. Approved.
10. motors.py sends: SET_SPEED 30 50
```

### 6.3 Safety Intervention Path (Example: Sudden Close Obstacle)

```
Situation: Front ultrasonic suddenly reads 12cm (below emergency_stop_distance_cm of 15cm).

1. Main loop SENSE phase reads SensorState
2. Main loop THINK phase: safety.check_continuous(sensor_state)
3. safety.py detects: front distance 12cm < emergency threshold 15cm
4. safety.py returns: EMERGENCY_STOP condition
5. Main loop skips inference entirely
6. Main loop ACT phase: motors.e_stop() — sends E_STOP to ESP32
7. ESP32 immediately sets both motors to 0 PWM
8. safety.py logs safety event: "E_STOP triggered, front obstacle at 12cm"
9. Main loop enters stopped state, waits for obstacle to clear
10. When front ultrasonic reads > warning_distance_cm: send RESET, resume normal operation
```

---

## 7. Constitutional Compliance Summary

Every module in the system maps back to specific SOUL.md articles. This is not decoration — it is the design requirement.

| SOUL.md Article | Implementation Location | How Enforced |
|---|---|---|
| **Art. 1.3 — Evolution** | `evolution.py` | Robot scores itself and proposes improvements |
| **Art. 1.4 — Steward, Not Sovereign** | `evolution.py`, `safety.py` | Human approval required for safety-affecting changes |
| **Art. 2 — Truth** | `logger.py`, `inference.py` | Logs are never falsified. Uncertainty is reported. Inference confidence is tracked. |
| **Art. 4 — Irreversibility** | `safety.py` | Commands assessed for reversibility before execution |
| **Art. 5 — Cascading Consequences** | `safety.py` | Stopping distance calculated: "Can I stop in time at this speed given this distance?" |
| **Art. 12 — Safety Hierarchy** | `safety.py` | Hard-coded priority order in all decision paths |
| **Art. 13 — Physical Action Protocols** | `main.py` loop structure | Pre-verify (THINK), monitor (ACT), confirm (EVALUATE) |
| **Art. 14 — Fail-Safe Defaults** | ESP32 watchdog, `safety.py` | When in doubt, stop. When sensors disagree, trust danger. When communication lost, safe state. |
| **Art. 15 — Authorization Levels** | `safety.py` | Every action classified by risk level |
| **Art. 17 — Logging** | `logger.py` | All decisions logged. Safety log is append-only. |
| **Art. 18 — Error Acknowledgment** | `logger.py`, `evolution.py` | Errors logged honestly, used for learning |
| **Art. 22 — Growth Within Principles** | `evolution.py` | Cannot propose weakening safety margins |

---

## 8. Deployment and Development Workflow

```
1. Claude Code (on WSL workstation) writes/edits code in:
   /mnt/c/Users/homet/Documents/EvoBot/code/

2. Deploy to Pi:
   scp -r code/ evobot:~/evobot/src/
   scp configs/ evobot:~/evobot/configs/

3. SSH to Pi, activate venv, run:
   ssh evobot
   cd ~/evobot
   source venv/bin/activate
   python3 -u src/main.py

4. During development: run manually, watch output, iterate
5. Once stable: create systemd service for autonomous operation
6. Logs accumulate on Pi in ~/evobot/logs/
7. SCP logs back to workstation for analysis if needed
```

---

## 9. Future Considerations (Out of Scope for v1, Documented for Reference)

These are acknowledged but not implemented in the initial architecture:

- **Multi-sensor fusion:** Combining ultrasonic, IMU, camera, and encoder data into a unified world model. v1 treats each sensor independently.
- **SLAM / mapping:** v1 has no persistent map. The robot reacts to the current moment.
- **Voice (TTS/STT):** Architecture supports it (abstracted interfaces in ARCHITECTURE_VISION.md), but not wired into v1.
- **Arm control:** Future SO-101 integration would add a new module (`arm.py`) with its own serial or I2C connection.
- **Multi-robot coordination:** The Pi fleet is available, but v1 is a single robot.
- **Hardware E_STOP button:** Should be wired directly to ESP32 or motor driver, independent of all software. Strongly recommended before autonomous operation.

---

*This document was written as the software architecture specification for EvoBot reference-01. It defines the contract that all implementation code must follow. When code disagrees with this document, fix the code.*

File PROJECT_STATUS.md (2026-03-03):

# EvoBot - Recursive Self-Evolving Robot

## Overview
A Raspberry Pi 3-based mobile robot that recursively self-evolves its own software. Claude is full architect (mechanics, electronics, software, safety, iteration); Scott handles physical assembly, wiring, and fabrication.

## Current Phase: PHYSICAL BUILD IN PROGRESS

### What's Done
- **Bottom deck:** Laser cut from plywood, all holes and features verified
- **Motor mounts:** STL generated, 3MF slicer project ready, printing
- **Sensor brackets:** Redesigned as L-bracket with channel rails (v2), STL clean
- **All STL parts:** motor_mount, caster_skid, standoff, sensor_bracket, webcam_mount
- **All DXF plates:** bottom_deck, top_deck (with bracket bolt holes), all_parts
- **Pi code:** Written (main.py, motors.py, sensors.py, inference.py, safety.py, evolution.py, logger.py) — NOT deployed to Pi yet
- **ESP32 firmware:** PlatformIO project written — NOT compiled/flashed yet
- **Pi 3 (Board #1):** Configured at 192.168.1.51, SSH key auth, project dirs ready

### What's Next
- Print remaining STL parts (caster skid, standoffs, sensor brackets, webcam mount)
- Laser cut top deck
- Assemble chassis: mount motors, caster, standoffs, wire Pi + ESP32
- Deploy Pi code, compile/flash ESP32
- First power-on test

## Hardware
- **Brain:** Raspberry Pi 3 Model B Rev 1.2 — Board #1, serial c28bf021
- **OS:** Raspbian Bookworm 12 (kernel 6.12.47, armv7l)
- **Static IP:** 192.168.1.51
- **Hostname:** evobot
- **SSH:** `ssh evobot` (key auth, ~/.ssh/evobot_ed25519)

## Network
- **LAN:** 192.168.1.0/24
- **Gateway:** 192.168.1.1 (confirmed)
- **DNS:** 192.168.1.1
- **Other devices:** Sensor Pi at .48, Home Assistant at .151

## Project Structure (Workstation)
```
Documents/EvoBot/
├── PROJECT_STATUS.md    ← this file
├── docs/                ← setup guides, architecture notes
├── code/                ← robot software (mirrored to Pi)
├── configs/             ← config files, systemd units
├── logs/                ← session logs, debug output
├── hardware/            ← photos, wiring diagrams, parts inventory
└── builds/reference-01/ ← build-specific files
    └── hardware/cad/    ← generate_stl.py, generate_dxf.py, STLs, DXFs
```

## Project Structure (Pi - /home/scott/evobot/)
```
/home/scott/evobot/
├── README.md            ← on-device documentation
├── src/                 ← robot source code
├── configs/             ← local config copies
└── logs/                ← runtime logs
```

## CAD Status
- **generate_stl.py:** 5 parts — motor_mount, caster_skid, standoff, sensor_bracket, webcam_mount
- **generate_dxf.py:** bottom_deck, top_deck (with sensor bracket bolt holes), all_parts
- **Sensor bracket v2:** L-bracket with channel rails, real M3 bolt holes (box_with_holes_mesh), axis-aligned geometry, 0 non-manifold edges
- **Top deck DXF:** Updated with 4x M3 bracket bolt holes (2 per sensor, 35mm apart)

## Build Photos
- `hardware/bottom_deck_cut.jpg` — Laser-cut bottom deck (plywood, all features cut/engraved)

## Setup Log
- **2026-02-24:** Project created. Pi #1 configured at .51. SSH key auth. Project dirs on Pi.
- **2026-03-02:** Bottom deck laser cut. Motor mounts printing. Sensor bracket redesigned (L-bracket v2). Top deck DXF updated with bracket bolt holes. All STL/DXF files regenerated.

## SSH Access
```bash
# From WSL (alias configured in ~/.ssh/config):
ssh evobot

# Or explicitly:
ssh -i ~/.ssh/evobot_ed25519 scott@192.168.1.51
```

## MAC Addresses
- **eth0:** B8:27:EB:8B:F0:21
- **wlan0:** B8:27:EB:DE:A5:74

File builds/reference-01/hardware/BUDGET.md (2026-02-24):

# EvoBot Budget Tracker

## Parameters (Human-Controlled)

| Parameter | Value | Set By | Last Updated |
|---|---|---|---|
| **Hard Ceiling** | $1,000.00 | Scott Whitney | 2026-02-24 |
| **Current Unlocked** | $0.00 | Reward program | 2026-02-24 |
| **Spent to Date** | $0.00 | — | 2026-02-24 |
| **Available** | $0.00 | Unlocked - Spent | 2026-02-24 |

---

## Reward Milestones

| # | Milestone | Unlocks | Status | Date Achieved |
|---|---|---|---|---|
| R1 | v1 drives and avoids obstacles (from pile, $0) | $50 | PENDING | — |
| R2 | v1 self-evaluates and proposes code improvement | +$100 | LOCKED | — |
| R3 | v1 successfully self-evolves a behavior | +$100 | LOCKED | — |
| R4 | v2 platform upgrade justified by v1 learnings | +$150 | LOCKED | — |
| R5 | Perception system working (camera + SLAM) | +$200 | LOCKED | — |
| R6 | Voice interaction working (TTS + STT) | +$200 | LOCKED | — |
| R7 | Arm integration (SO-101 or equivalent) | +$200 | LOCKED | — |

**Total possible unlocked: $1,000**

---

## Purchase Log

| Date | Item | Milestone Ref | Amount | Running Total | Approved By |
|---|---|---|---|---|---|
| — | *No purchases yet — v1 is a $0 build* | — | — | $0.00 | — |

---

## Rules

1. Claude recommends. Scott approves.
2. Every purchase references a milestone or specific capability it unblocks.
3. No speculative buying — don't buy Phase 5 parts during Phase 1.
4. Build/fabricate before buying.
5. Hard ceiling is $1,000, adjustable by Scott only.
6. Unlocked budget accumulates — unspent funds from earlier milestones carry forward.

---

*Updated after each purchase or milestone achievement.*

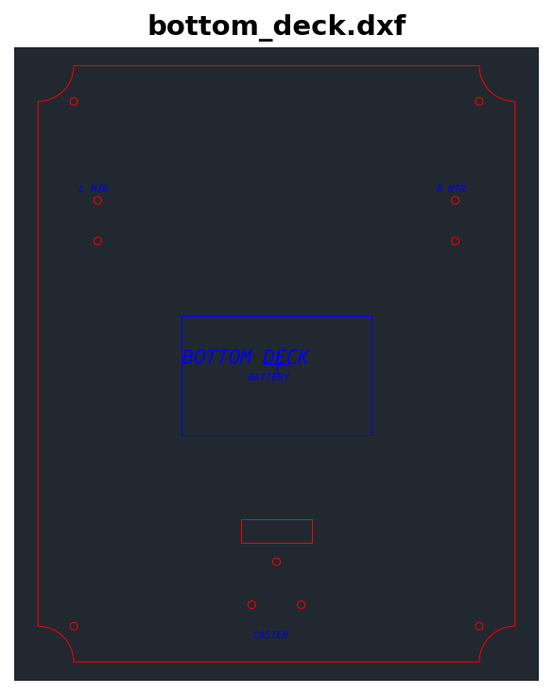
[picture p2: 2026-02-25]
builds/reference-01/hardware/cad/bottom_deck_preview.png

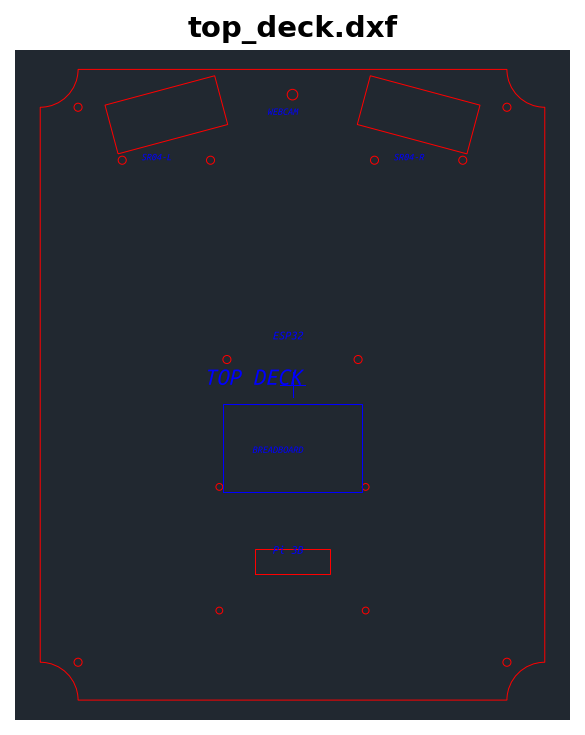
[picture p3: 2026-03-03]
builds/reference-01/hardware/cad/top_deck_preview.png

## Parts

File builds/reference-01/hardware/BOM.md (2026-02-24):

# EvoBot v1 Bill of Materials

## Build Target
**Cost: $0** — entirely from shop stock
**Config: 2WD differential drive + rear caster (3D printed or improvised)**

---

## Drive System

| Part | Source | Qty | Notes |
|---|---|---|---|
| TT Geared DC Motor w/ Encoder (yellow) | Shop stock (M5) | 2 | Left + right drive. 3-6V, ~200 RPM. Encoders for feedback. |
| TT Motor Wheels | Shop stock (X1) | 2 | Front left + right. Fits TT motor shaft. |
| Caster wheel | **3D print (TPU/PETG)** or ball from junk bin | 1 | Rear center. Ball caster or swivel. |
| Arduino Motor Shield (L293D) | Shop stock (D5) | 1 | Drives both TT motors. Controlled by ESP32/Pico over serial, or direct from Pi GPIO. |

### Drive Notes
- 2WD differential: two powered front wheels + one rear caster
- Turning: spin motors opposite directions (zero-radius turn capable)
- Straight line: both motors same speed with encoder PID correction
- TT motors are weak (~0.5kg/cm torque) but fine for a lightweight wood chassis

---

## Brain + Co-Processors

| Part | Source | Qty | Role |
|---|---|---|---|
| Raspberry Pi 3B (#1, c28bf021) | Allocated (C1) | 1 | Main brain — logic, WiFi, camera, SSH |
| ESP32 Dev Board | Shop stock (C5) | 1 | Motor control + encoder reading (real-time) |
| Pi Pico or Arduino | Shop stock (C3/C7) | 1 | Safety watchdog (optional for v1, recommended) |

### Compute Notes
- Pi 3 runs main Python logic, camera, WiFi, inference calls
- ESP32 handles motor PWM + encoder counting (needs microsecond timing)
- Pi ↔ ESP32: serial UART (3.3V, no level shifter needed)
- Safety watchdog: independent MCU that kills motor power if Pi stops heartbeating

---

## Sensors (v1 minimum)

| Part | Source | Qty | Role |
|---|---|---|---|
| HC-SR04 Ultrasonic | Shop stock (S1) | 2 | Front-facing obstacle detection (left + right) |
| IMU (MPU6050) | Shop stock (S4) | 1 | Orientation, tilt detection, acceleration |
| Wheel encoders | Built into TT motors (M5) | 2 | Odometry, speed feedback |
| USB Webcam | Shop stock (V1) | 1 | Vision — object detection, navigation |

### Sensor Notes
- HC-SR04 needs 5V trigger but 3.3V echo → level shifter (B4) or voltage divider
- MPU6050 is I2C, 3.3V native — direct to Pi or ESP32
- Webcam goes to Pi USB — OpenCV for image processing

---

## Power

| Part | Source | Qty | Notes |
|---|---|---|---|
| 2S LiPo/Li-Ion pack | Shop stock (P6) | 1 | ~7.4V nominal. Powers motors directly through driver. |
| Buck converter (5V out) | Shop stock (P3) | 1 | Steps 7.4V → 5V for Pi + ESP32 power |
| Wiring + terminal blocks | Shop stock (X2/X3) | — | Power distribution |

### Power Notes
- 2S pack (7.4V) is within TT motor range (they tolerate up to ~6-8V)
- Buck converter provides clean 5V 3A for Pi (needs at least 2.5A)
- Motor driver takes battery voltage directly, logic level from 5V rail
- Kill switch: physical toggle on battery lead (Constitution Art. 14 — easy emergency stop)

---

## Chassis

| Part | Source | Method | Notes |
|---|---|---|---|
| Base plate | Plywood/MDF 3-5mm | Laser cut | ~250x200mm rectangle with motor mounts, rounded corners |
| Upper deck | Plywood/MDF 3-5mm | Laser cut | Pi + electronics mounting plate, standoffs from base |
| Motor mounts | PETG 3D print | FDM | Clips/brackets to hold TT motors to base plate |
| Caster mount | PETG/TPU 3D print | FDM | Rear ball caster bracket |
| Standoffs | M3 x 30mm | Shop stock or 3D print | Deck-to-deck spacing |

### Chassis Notes
- Parametric design — SVG for laser, STEP for 3D parts
- Two-deck architecture: bottom = motors + battery, top = Pi + sensors + camera
- Everything bolts together — no glue — so it's modifiable
- Hand-cut alternative: print SVG at 1:1 on paper, trace to wood, jigsaw cut

---

## Interconnect

| Part | Source | Qty | Notes |
|---|---|---|---|
| Level shifter (3.3V↔5V) | Shop stock (B4) | 1 | For HC-SR04 echo pins |
| Jumper wires (M-F, F-F) | Shop stock (X4) | ~30 | Prototyping connections |
| Breadboard (mini) | Shop stock (B1 area) | 1 | Sensor/power distribution |
| USB cable (micro) | Shop stock | 1 | Pi power from buck converter |

---

## Total Cost

| Category | Cost |
|---|---|
| Drive | $0 |
| Compute | $0 |
| Sensors | $0 |
| Power | $0 |
| Chassis materials | $0 (scrap wood + filament on hand) |
| Interconnect | $0 |
| **TOTAL** | **$0** |

---

## What v1 Can Do

With these parts, v1 will be able to:
- [x] Drive forward, backward, turn (differential drive)
- [x] Know its wheel speed and distance (encoders)
- [x] Detect obstacles (ultrasonic)
- [x] Know its orientation (IMU)
- [x] See the world (USB webcam)
- [x] Think (Pi 3 + Ollama on LAN)
- [x] Be remotely operated (SSH/WiFi)
- [x] Emergency stop (physical kill switch)
- [x] Self-evaluate movement accuracy (encoder vs commanded)
- [x] Log all decisions and actions (Constitution Art. 17)

## What v1 Cannot Do (Yet)

- Voice interaction (no TTS/STT in v1)
- Navigate autonomously beyond obstacle avoidance
- Manipulate objects (no arms)
- Run untethered for long durations (2S pack, limited capacity)
- Self-modify its own hardware

---

*v1 is proof of concept. It proves the brain works. The body upgrades come after.*

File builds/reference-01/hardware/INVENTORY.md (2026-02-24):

# EvoBot Hardware Inventory

**Date inventoried:** 2026-02-24
**Inventoried by:** Scott Whitney
**Status:** Initial catalogue — quantities approximate, to be refined

---

## Motors

| # | Type | Description | Qty | Voltage | Notes |
|---|---|---|-----|---|---|
| M1 | BLDC w/ Hall | Hoverboard hub motors | 2+ | 36V nominal | Hall effect feedback, paired with Riorand controllers |
| M2 | Stepper | Various sizes (NEMA 17, 23, etc.) | Multiple | 12-48V | Range from 3D printer size to CNC size |
| M3 | Hobby Servo | Standard and micro sizes | Multiple | 5-6V | Both continuous rotation and standard position |
| M4 | DC Brushed | Various | Multiple | Various | Less preferred — want better control options |
| **M5** | **TT Geared DC w/ Encoder** | **Yellow gearbox motor** | **4** | **3-6V** | **v1 DRIVE MOTORS — confirmed in stock, cheap and ubiquitous** |

---

## Motor Drivers / Controllers

| # | Type | Model/Marking | Qty | Notes |
|---|---|---|-----|---|
| D1 | High-current H-Bridge | **BTS7960** (43A) | 1+ | For large DC motors — dual H-bridge, PWM capable |
| D2 | BLDC Controller | Riorand | 1+ | For hoverboard-style hall effect BLDC motors |
| D3 | CNC Stepper Drivers | Large (DM542/similar) | Multiple | For CNC-class steppers |
| D4 | 3D Printer Stepper Drivers | A4988, DRV8825 | Multiple | For NEMA 17 class steppers |
| **D5** | **Arduino Motor Shield** | **L293D-based (Motor A&B)** | **1+** | **v1 DRIVE — drives TT motors directly, 5-12V** |
| D6 | Arduino Motor Shields | Older era shields | Multiple | Various, to be tested |

---

## Sensors

| # | Type | Model/Marking | Qty | Interface | Notes |
|---|---|---|-----|---|---|
| S1 | Ultrasonic | HC-SR04 (or similar) | Multiple | GPIO | Distance/obstacle detection |
| S2 | PIR Motion | Standard | Multiple | GPIO | Motion detection |
| S3 | Temperature/Humidity | DHT11 | Multiple | GPIO | Already proven on sensor Pi project |
| S4 | IMU/Accelerometer | MPU6050 or similar | 1+ | I2C | Balance, orientation, motion sensing |
| S5 | Hall Effect | Discrete sensors | Multiple | GPIO | Position sensing, RPM |
| S6 | Light Sensor | LDR / photodiode | Multiple | Analog/GPIO | Ambient light detection |
| S7 | Rotary Encoder | Standard | Multiple | GPIO | Precise rotation measurement |
| S8 | Opto-interrupter | Emitter/detector pair | Multiple | GPIO | Wheel encoder style — light-blocking slot sensors |
| S9 | Limit Switch | Mechanical | Multiple | GPIO | End-stop / contact detection |

---

## Compute Boards

| # | Type | Model | Qty | Notes |
|---|---|---|-----|---|
| C1 | Raspberry Pi 3B | Rev 1.2 | 6-7 | Tested stock (1 allocated to EvoBot, 6 remaining) |
| C2 | Raspberry Pi Zero | Various | Multiple | Low power, compact |
| C3 | Raspberry Pi Pico | RP2040 | Multiple | Microcontroller, real-time GPIO |
| C4 | Orange Pi | v1 (w/ HDMI, USB, desktop Linux) | ~6-7 | Weak but usable as dedicated task nodes (camera, motor ctrl, sensors) |
| C5 | ESP32 Dev | Standard dev boards | Multiple | WiFi+BT, dual core, ADC |
| C6 | ESP32-CAM | AI Thinker or similar | 1+ | Camera + WiFi in one module |
| C7 | Arduino Uno | Clone | Multiple | 5V ATmega328, classic |
| C8 | Arduino Mega | Clone | Multiple | More GPIO, more memory |
| C9 | Arduino Micro | Clone | Multiple | Compact ATmega32U4 |
| C10 | Teensy | Model TBD | 1+ | High-speed, USB native |
| C11 | Adafruit RP2040 boards | Pico-based | Multiple | Adafruit ecosystem |
| C12 | Seeeduino XIAO | SAMD21/RP2040/nRF52840 | Multiple | Tiny, versatile |

---

## Power

| # | Type | Description | Qty | Notes |
|---|---|---|-----|---|
| P1 | Li-Ion cells/packs | Various | Multiple | Can build custom packs |
| P2 | LiFePO4 cells/packs | Various | Multiple | Safer chemistry, lower energy density |
| P3 | Buck converters | Various ratings | Multiple | Step-down voltage regulation |
| P4 | Hoverboard batteries | 36V packs | 2+ | From hoverboard teardowns |
| P5 | Custom pack capability | Spot welder / holder | — | Can build 12V, 24V, 36V packs to spec |

| **P6** | **2S LiPo/Li-Ion packs** | **Ready to go** | **Multiple** | **~7.4V — good for servo power, could run TT motors directly** |

*v1 power: 2S pack (7.4V) for motors + buck to 5V for Pi. Can build 3S (12V) when needed.*

---

## Displays / Output

| # | Type | Description | Qty | Notes |
|---|---|---|-----|---|
| O1 | LCD | Arduino-style (1602/2004 I2C) | Multiple | Classic character displays |
| O2 | Color Display | TFT/IPS (SPI) | Multiple | Graphical, various sizes |
| O3 | Misc Displays | Other types | Multiple | To be identified |
| O4 | Speakers | Hardwired + USB | Multiple | Audio output for TTS |
| O5 | Microphones | Hardwired + USB | Multiple | Audio input for STT |
| O6 | LED Drivers | Various | Multiple | For indicator/status LEDs or strips |

---

## Cameras

| # | Type | Model | Qty | Notes |
|---|---|---|-----|---|
| V1 | USB Webcam | Various | Multiple | Plug-and-play on Pi |
| V2 | ESP32-CAM | AI Thinker or similar | 1+ | Standalone WiFi camera node |

---

## Breakout Boards / Modules

| # | Type | Model/Marking | Qty | Notes |
|---|---|---|-----|---|
| B1 | ADC | ADS1115 or similar | Multiple | 16-bit, I2C — reads analog sensors on Pi |
| B2 | RTC | DS3231 or similar | Multiple | Real-time clock, I2C |
| B3 | SD Card Module | SPI breakout | Multiple | Data logging |
| B4 | Level Shifter | 3.3V↔5V | Multiple | Critical for Pi↔Arduino/5V sensor interfacing |
| B5 | Relay Module | Mechanical | Multiple | Switching loads |
| B6 | SSR | Solid State Relay | Multiple | Silent/fast switching |
| B7 | Opto-isolator | Various | Multiple | Signal isolation between circuits |

---

## Mechanical / Structural

| # | Type | Description | Qty | Notes |
|---|---|---|-----|---|
| **X1** | **TT Motor Wheels** | **Yellow motor compatible** | **3** | **v1 — 1 short for 4WD, fine for 2WD+caster or 3-wheel config** |
| X2 | Wiring | Assorted gauge | Bulk | Hook-up wire, various gauges |
| X3 | Terminal Blocks | Various | Multiple | Power distribution, connections |
| X4 | Misc Connectors | Various | Multiple | JST, Dupont, barrel, etc. |

---

## Fabrication Capability (In-House)

| Tool | Type | Material | Notes |
|---|---|---|---|
| Plasma CNC | Cutting | Metal | Heavy structural parts |
| Laser CNC | Cutting/engraving | Wood, soft materials | Chassis plates, mounting |
| 3D Printer | FDM | PETG, Flex (TPU) | Brackets, mounts, enclosures, wheels |
| CNC Router | Milling | Wood | Larger structural — currently outsourced, prefer in-house |

*Strong fabrication capability means chassis/frame/mounts can be custom-designed and built to spec rather than purchased.*

---

## Summary

**Total unique item categories:** 45+
**Compute boards available:** 20+ across 12 types
**Fabrication methods:** 4 (plasma, laser, 3D print, CNC route)
**Strongest assets:** Deep motor selection, full voltage range, in-house fabrication, massive compute board variety
**Key gaps to fill:** Wheels (make or buy), chassis design, Pi Camera (CSI), servo driver board (PCA9685), dedicated power distribution board

---

*This inventory represents starting stock. Additional parts can be purchased as needed — see PROCUREMENT.md (TBD).*

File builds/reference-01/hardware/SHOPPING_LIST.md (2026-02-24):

# EvoBot Shopping List

## v1 Build: $0 Target

**v1 requires NO purchases.** All parts sourced from shop stock + fabrication.

| v1 Need | Solved By | Cost |
|---|---|---|
| Drive motors | 4x TT yellow geared DC w/ encoder (in stock) | $0 |
| Wheels | 3x TT wheels (in stock), caster 3D printed | $0 |
| Motor driver | Arduino motor shield L293D (in stock) | $0 |
| Brain | Pi 3B #1 (allocated) | $0 |
| Co-processor | ESP32 dev board (in stock) | $0 |
| Sensors | HC-SR04, MPU6050, webcam (all in stock) | $0 |
| Battery | 2S Li-Ion pack (in stock, ready to go) | $0 |
| Buck converter | 5V output (in stock) | $0 |
| Chassis | Laser-cut scrap wood + 3D printed mounts | $0 |
| Level shifters | In stock | $0 |
| Wiring/connectors | In stock | $0 |
| **TOTAL** | **Everything from the pile** | **$0** |

---

## Post-v1: When Budget Unlocks ($50 after R1 milestone)

These purchases would improve v1 or prepare for v2. Not needed until v1 proves itself.

| Item | Why | Est. Price | Priority |
|---|---|---|---|
| PCA9685 servo driver board | 16-channel PWM over I2C, clean servo/motor control | $5-8 | High — enables multi-servo future |
| Pi Camera Module v2 or v3 | CSI interface, better latency/quality than USB webcam | $25-30 | Medium — USB webcam works for now |
| M3 standoff assortment kit | Proper mounting hardware (currently improvising) | $8-12 | Medium — QoL |
| XT60 connector set | Standard battery connectors for safe hot-swap | $5-8 | Low — can solder direct for now |

---

## Future Phases (Locked Until Milestones)

| Item | Phase | Unlocked At | Est. Price | Notes |
|---|---|---|---|---|
| Upgraded motors (JGB37-520 w/ encoder, 12V) | v2 | R4 ($300 cumulative) | $15-25/pair | Real torque for heavier platform |
| 3S LiFePO4 pack (12V) | v2 | R4 | $20-40 | Build from cells or buy |
| LiDAR (RPLIDAR A1 or similar) | Phase 2 | R5 ($500 cumulative) | $80-100 | SLAM-quality mapping |
| SO-101 arm kit or servo set | Phase 5 | R7 ($1000 cumulative) | $100-300 | 6-DOF manipulation |
| Charging dock components | Phase 6 | R7 | $20-40 | Autonomous recharging |

---

## Procurement Rules

1. **$0 until v1 milestone (R1) is achieved**
2. Claude recommends, Scott approves — see `BUDGET.md` for tracking
3. Fabricate before buying (3D print, laser cut, build from stock)
4. Amazon for speed, AliExpress for bulk when time permits
5. Every purchase logged in `BUDGET.md` with milestone reference

---

*Nothing on this list gets bought until the pile proves itself.*

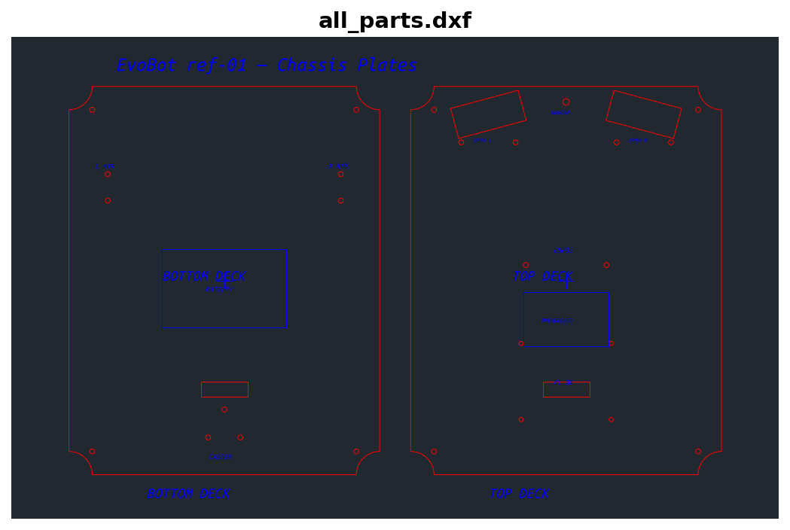
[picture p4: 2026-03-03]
builds/reference-01/hardware/cad/all_parts_preview.png

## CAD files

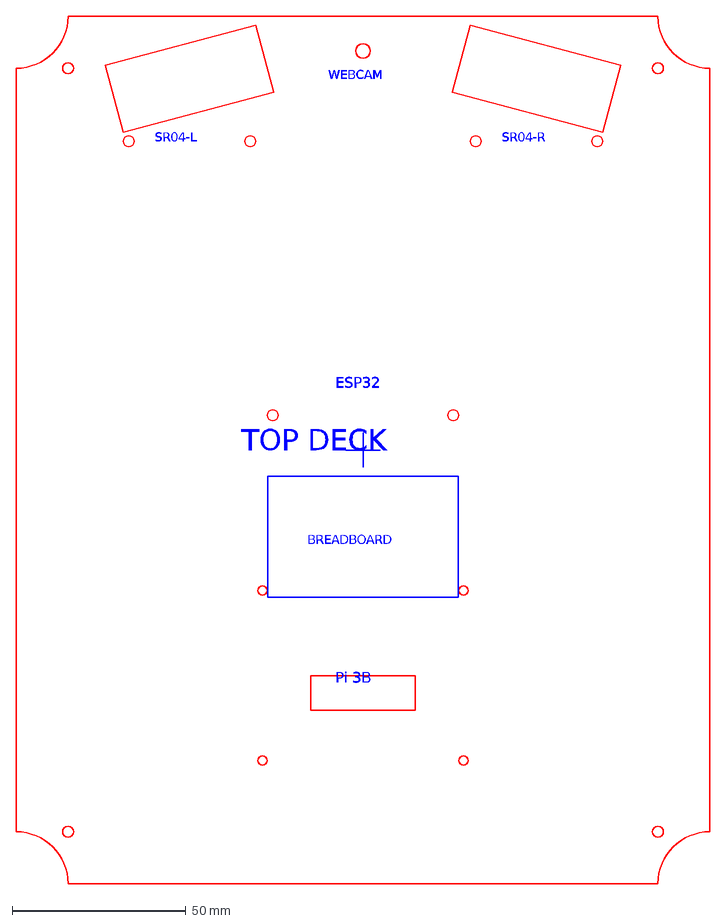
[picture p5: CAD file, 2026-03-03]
builds/reference-01/hardware/cad/top_deck.dxf
TOP DECK
Pi 3B
ESP32
BREADBOARD
SR04-L
SR04-R
WEBCAM

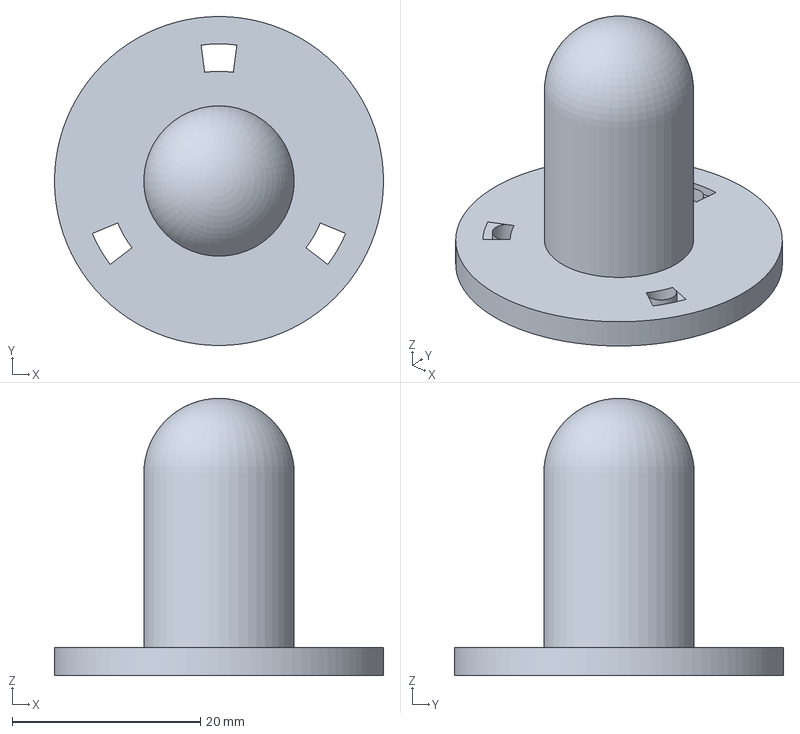
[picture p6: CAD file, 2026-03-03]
builds/reference-01/hardware/motor_mount.3mf
35.0 x 35.0 x 29.5 mm

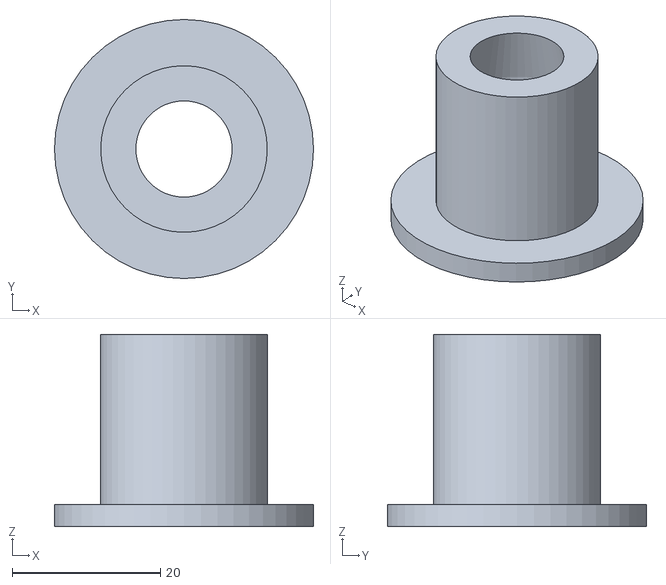
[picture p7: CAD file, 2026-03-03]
builds/reference-01/hardware/cad/ball_caster.stl
35.0 x 35.0 x 26.0

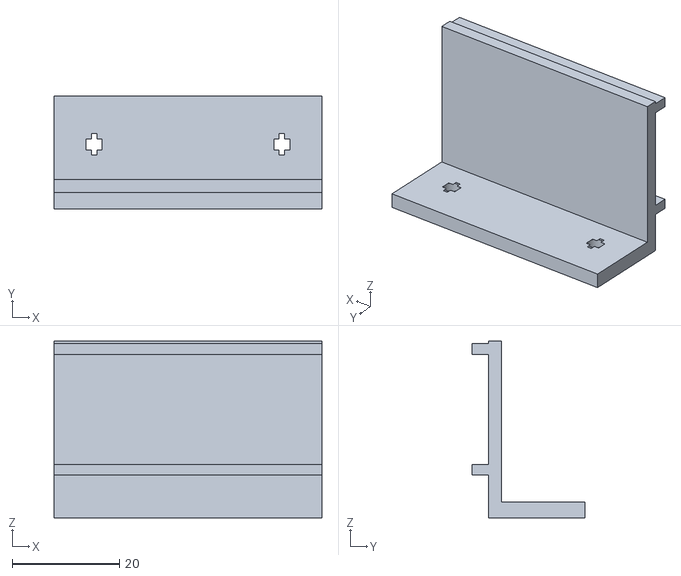
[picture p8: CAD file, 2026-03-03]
builds/reference-01/hardware/cad/sensor_bracket.stl
50.0 x 21.0 x 33.0

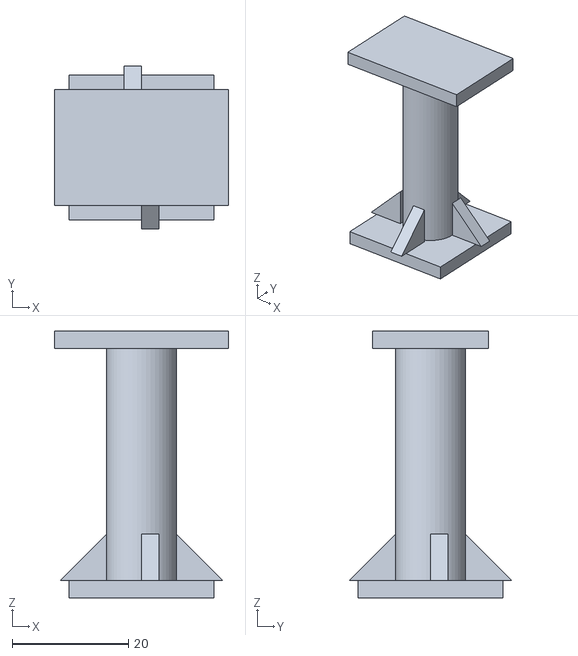
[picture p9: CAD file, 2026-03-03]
builds/reference-01/hardware/cad/webcam_mount.stl
30.0 x 28.0 x 46.0

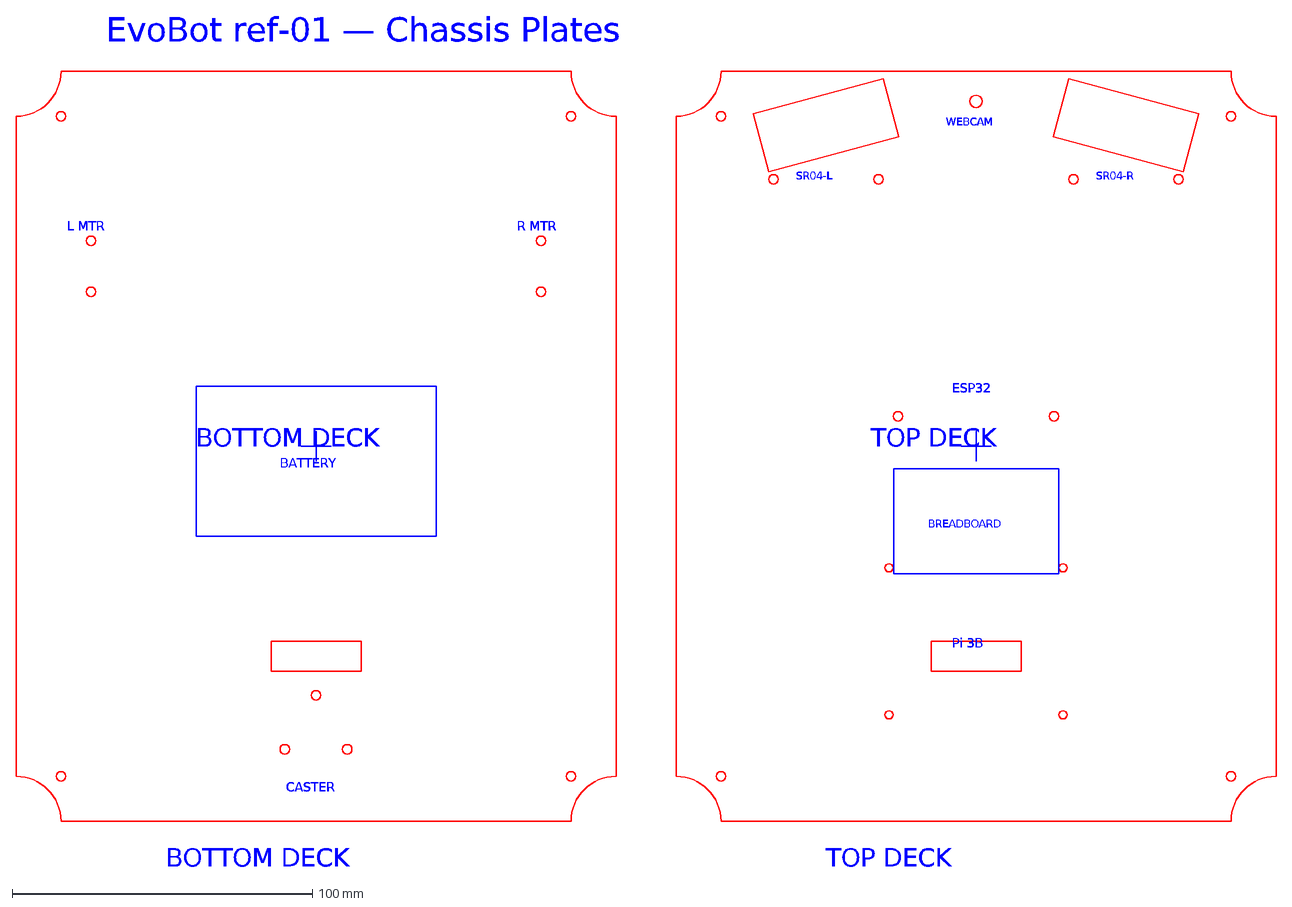
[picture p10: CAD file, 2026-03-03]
builds/reference-01/hardware/cad/all_parts.dxf
BOTTOM DECK
BATTERY
L MTR
R MTR
CASTER
TOP DECK
Pi 3B
ESP32
BREADBOARD
SR04-L
SR04-R
WEBCAM
EvoBot ref-01 — Chassis Plates

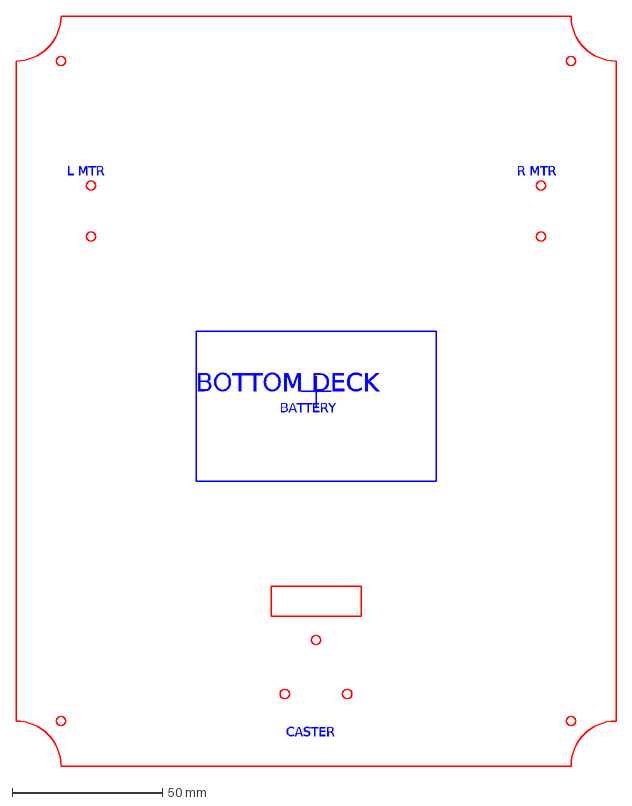
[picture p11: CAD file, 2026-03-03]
builds/reference-01/hardware/cad/bottom_deck.dxf
BOTTOM DECK
BATTERY
L MTR
R MTR
CASTER

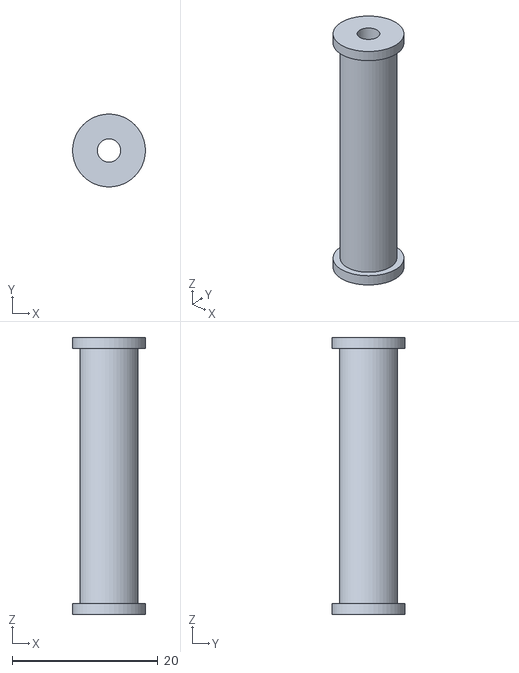
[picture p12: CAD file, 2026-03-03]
builds/reference-01/hardware/cad/standoff.stl
10.0 x 10.0 x 38.0

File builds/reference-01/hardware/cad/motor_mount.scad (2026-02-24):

// EvoBot reference-01 — TT Motor Mount Clip (print 2x)
// Open in OpenSCAD → Render (F6) → Export STL (F7)

// Parametric dimensions (mm)
channel_w   = 23;   // inside width
channel_h   = 19;   // inside height (depth of U)
wall        = 1.5;  // wall thickness
clip_len    = 30; // length along motor body
tab_w       = 8;   // bolt tab width
tab_t       = 3; // bolt tab thickness
hole_span   = 17; // M3 hole spacing
hole_dia    = 3.2; // M3 clearance

$fn = 48;

module motor_mount() {
    outer_w = channel_w + 2*wall;
    total_w = outer_w + 2*tab_w;
    total_h = channel_h + wall;

    difference() {
        union() {
            // U-channel body
            translate([-clip_len/2, -outer_w/2, 0])
                cube([clip_len, outer_w, total_h]);
            // Left tab
            translate([-clip_len/2, -total_w/2, 0])
                cube([clip_len, tab_w, tab_t]);
            // Right tab
            translate([-clip_len/2, outer_w/2, 0])
                cube([clip_len, tab_w, tab_t]);
        }
        // Channel cutout (open top)
        translate([-clip_len/2 - 1, -channel_w/2, wall])
            cube([clip_len + 2, channel_w, channel_h + 1]);
        // M3 bolt holes (4 total, 2 per side)
        for (sx = [-1, 1])
            for (sy = [-1, 1])
                translate([sx * hole_span/2, sy * (outer_w/2 + tab_w/2), -1])
                    cylinder(d=hole_dia, h=tab_t + 2);
    }
}

motor_mount();

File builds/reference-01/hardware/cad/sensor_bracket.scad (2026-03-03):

// EvoBot reference-01 — HC-SR04 Sensor Bracket (print 2x)
// L-bracket with channel rails for slide-in PCB retention
// Open in OpenSCAD → Render (F6) → Export STL (F7)

// Parametric dimensions (mm)
bracket_len    = 50;       // X dimension
base_w         = 18;       // Y dimension (base depth)
base_t         = 3;       // Z (base thickness)
wall_t         = 2.5;       // Y (back wall thickness)
wall_h         = 30;       // Z (wall height above base top)
rail_d         = 3;   // Y (rail protrusion)
rail_h         = 2;       // Z (rail thickness)
bot_rail_z     = 8;   // Z offset for bottom rail
board_gap      = 20.5;    // gap between rails (HC-SR04 height)
hole_span      = 35;    // M3 bolt hole spacing
mount_hole_dia = 3.2;         // M3 clearance

$fn = 48;

module sensor_bracket() {
    top_rail_z = bot_rail_z + rail_h + board_gap;

    difference() {
        union() {
            // Base plate
            cube([bracket_len, base_w, base_t]);
            // Back wall
            cube([bracket_len, wall_t, base_t + wall_h]);
            // Bottom rail
            translate([0, -rail_d, bot_rail_z])
                cube([bracket_len, rail_d, rail_h]);
            // Top rail
            translate([0, -rail_d, top_rail_z])
                cube([bracket_len, rail_d, rail_h]);
        }
        // M3 bolt holes through base
        for (sx = [-1, 1])
            translate([bracket_len/2 + sx*hole_span/2, base_w/2, -1])
                cylinder(d=mount_hole_dia, h=base_t + 2);
    }
}

sensor_bracket();

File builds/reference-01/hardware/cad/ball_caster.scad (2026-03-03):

// EvoBot reference-01 — Caster Skid / Drag Tip (v1)
//
// USE OPENSCAD to render: F6 (Render) → F7 (Export STL)
// Or use generate_stl.py which produces an equivalent STL directly.
//
// DESIGN:
//   Fixed hemisphere dome on a cylindrical stem with bolt-on flange.
//   No moving parts — the dome slides on the ground surface.
//   Works well for a lightweight (~500g) robot on smooth floors.
//   Can be upgraded to a ball caster later if needed.
//
// PRINT: Flange flat on bed. Dome at top has gentle overhang
//   but prints fine at this small size. No supports needed.
//
// MOUNT: Bolt flange to underside of bottom deck plate (3x M3).
//   The 3 bolt holes match the caster mount pattern on the deck.
//
// CROSS-SECTION (mounted orientation):
//
//        ========= DECK PLATE =========
//       |                               |
//       +----+                   +------+  <- flange (bolted to deck)
//            |                   |
//            |   stem (16mm OD)  |
//            |                   |
//            +---+           +---+
//                 \         /
//                  (  dome  )              <- hemisphere, slides on ground
//                   \     /
//                    (   )
//                     ---
//                   GROUND

// === Parameters (all in mm) ===

dome_radius = 8;                      // Hemisphere radius (ground contact)
stem_dia = dome_radius * 2;           // Stem matches dome diameter
flange_dia = 35;                      // Mounting flange outer diameter
flange_thick = 3;                     // Flange thickness

// Ride height: 29.5mm from deck bottom to ground
// = flange_thick + stem_height + dome_radius
// stem_height = 29.5 - 3 - 8 = 18.5mm
stem_height = 18.5;

mount_bolt_radius = 12;               // Matches DXF CASTER_BOLT_RADIUS
mount_hole_dia = 3.4;                 // M3 clearance

$fn = 60;

module caster_skid() {
    total_height = flange_thick + stem_height + dome_radius;

    difference() {
        union() {
            // Mounting flange (z=0 = on print bed)
            cylinder(d=flange_dia, h=flange_thick);

            // Cylindrical stem
            translate([0, 0, flange_thick])
                cylinder(d=stem_dia, h=stem_height);

            // Hemisphere dome (ground contact when mounted/flipped)
            translate([0, 0, flange_thick + stem_height])
                sphere(r=dome_radius);
        }

        // Cut off bottom half of sphere (below stem top)
        translate([0, 0, flange_thick + stem_height - dome_radius])
            translate([0, 0, -dome_radius])
                cube([flange_dia + 2, flange_dia + 2, dome_radius * 2], center=true);

        // 3x M3 mounting holes through flange (120° apart)
        for (i = [0:2])
            rotate([0, 0, i * 120 + 90])
                translate([mount_bolt_radius, 0, -1])
                    cylinder(d=mount_hole_dia, h=flange_thick + 2);
    }
}

caster_skid();

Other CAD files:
builds/reference-01/hardware/cad/caster_skid.stl
builds/reference-01/hardware/cad/standoff.scad
builds/reference-01/hardware/cad/motor_mount.stl
builds/reference-01/hardware/cad/webcam_mount.scad

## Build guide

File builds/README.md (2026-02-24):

# EvoBot Builds

## What Is a Build?

A "build" is one specific way to assemble an EvoBot. The EvoBot platform defines the software architecture, design philosophy, and constitutional governance. A build defines the specific hardware, wiring, configuration, and trade-offs for one particular robot.

**There is no single "correct" build.** The platform is designed to support many configurations depending on what parts you have, what you can afford, and what capabilities you want.

## Available Builds

| Build | Description | Cost | Status |
|---|---|---|---|
| [reference-01](reference-01/) | Mid-size 2WD, Pi 3B + ESP32, TT motors, local Ollama + Claude API | $0 (from parts on hand) | In progress |

## How Builds Differ

Builds can vary in any or all of these dimensions:

| Dimension | Example Variations |
|---|---|
| **Size** | Desktop (20cm), mid-size (40-60cm), large (60cm+) |
| **Drive** | 2WD differential, 4WD skid steer, mecanum, tracked |
| **Motors** | TT geared DC, NEMA 17 stepper, BLDC hoverboard, hobby servo |
| **Brain** | Pi 3B, Pi 4, Pi 5, Orange Pi, Jetson Nano |
| **Co-processor** | ESP32, Pi Pico, Arduino Mega, Teensy, none |
| **Inference** | Local Ollama, cloud-only (Claude/GPT), hybrid, edge TPU |
| **Power** | 2S LiPo (7.4V), 3S (12V), USB power bank, 36V hoverboard pack |
| **Sensors** | Ultrasonic only, ultrasonic + IMU, LiDAR, stereo camera |
| **Chassis** | Laser-cut wood, 3D printed, acrylic, aluminum, cardboard |
| **Arms** | None, SO-101, custom servo arm, gripper only |

## Creating a New Build

1. Copy `reference-01/` as a starting point (or start from scratch)
2. Create your directory: `builds/your-build-name/`
3. Include at minimum:
   - `README.md` — what makes this build different and why
   - `hardware/BOM.md` — bill of materials
   - `docs/TOPOLOGY.md` — your specific network/compute layout
   - `configs/` — any configuration files specific to this build
4. Submit a PR if you want it included in the repo

## What Stays at Platform Level

These files apply to ALL builds and live in the repo root or `docs/`:

| File | Scope |
|---|---|
| `docs/DESIGN_PHILOSOPHY.md` | Local-first principle, constitutional governance, self-evolution philosophy |
| `docs/SOUL.md` | Opengates Constitution — governs ALL builds |
| `docs/ARCHITECTURE_VISION.md` | Evolution roadmap, compute architecture concepts |
| `code/` | Core robot software (configurable per build) |
| `hardware/INVENTORY.md` | Reference-01's specific parts (other builds have their own) |

## The Goal

A community of builds, each learning from the others. Your build's self-evolution insights feed back into the platform. The platform gets smarter. Every build benefits.

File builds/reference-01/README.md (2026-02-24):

# Build: reference-01

## Summary

The first EvoBot build. A mid-size 2WD differential-drive robot built entirely from parts on hand ($0 initial cost), using a Raspberry Pi 3B as the brain, an ESP32 for real-time motor control, and a hybrid local/cloud inference stack.

**This is ONE way to build an EvoBot.** See [builds/README.md](../README.md) for other configurations.

## Key Choices (and Alternatives)

| Decision | This Build Chose | Why | Alternatives |
|---|---|---|---|
| **Drive** | 2WD + caster | Simple, cheap, sufficient for v1 | 4WD skid steer, mecanum, tracked |
| **Motors** | TT yellow geared DC | Free (in stock), ubiquitous, encoder-equipped | NEMA 17 stepper, geared 12V DC, BLDC |
| **Brain** | Pi 3B (1GB, armv7l) | Available, proven, WiFi built-in | Pi 4/5, Orange Pi, Jetson Nano |
| **Co-processor** | ESP32 | WiFi+BT, dual-core, cheap, real-time | Pi Pico, Arduino Mega, Teensy |
| **Inference** | Ollama (LAN, 8GB VRAM) + Claude API fallback | Local-first, degrades gracefully offline | Cloud-only, edge TPU, all-local small model |
| **Battery** | 2S Li-Ion (7.4V) | Available, safe, sufficient for TT motors | 3S (12V), USB power bank, 36V pack |
| **Chassis** | Laser-cut wood (parametric) | Free (scrap wood), fast iteration | 3D printed, acrylic, hand-cut, aluminum |
| **Camera** | USB webcam | Available, plug-and-play | Pi Camera CSI, ESP32-CAM, stereo |

## What You Need to Reproduce This Build

### Minimum Hardware
- 1x Raspberry Pi 3B (or any Pi with WiFi)
- 1x ESP32 dev board
- 2x TT geared DC motor with encoder
- 2x TT motor wheels
- 1x Caster wheel (or 3D print one)
- 1x L293D motor driver (shield or breakout)
- 2x HC-SR04 ultrasonic sensor
- 1x MPU6050 IMU
- 1x USB webcam
- 1x 2S battery pack + buck converter to 5V
- 1x Level shifter (3.3V↔5V)
- Wood or similar for chassis (~3-5mm, 250x200mm minimum)
- Assorted jumper wires, standoffs, screws

### Inference Stack Options

This build uses a local Ollama server with 8GB VRAM GPU. **You do NOT need this.** The inference interface is abstracted — configure whichever backend you have:

| If You Have... | Configure As | Performance |
|---|---|---|
| GPU + Ollama on LAN | `inference.local.url = "http://<ollama-ip>:11434"` | Best: fast, free, private, works offline |
| CPU-only Ollama on LAN | Same as above | Good: slower but still local and free |
| Ollama on the Pi itself | `inference.local.url = "http://localhost:11434"` | Slow: Pi 3 is underpowered for LLMs, but works for tiny models |
| No local LLM, cloud only | `inference.cloud.provider = "anthropic"` | Fine: requires internet, costs per call, but works great |
| Both (this build) | Local primary, cloud fallback | Recommended: best of both worlds |

### Network Layout

See [docs/TOPOLOGY.md](docs/TOPOLOGY.md) for the full connection map.

```
[Workstation/WSL] ──SSH──→ [Pi 3B @ 192.168.1.51]
                                │
                           [UART Serial]
                                │
                           [ESP32: motors + encoders + safety]
```

## Build-Specific Files

```
builds/reference-01/
├── README.md              ← you are here
├── hardware/
│   ├── BOM.md             ← full bill of materials
│   ├── BUDGET.md          ← spending tracker + reward program
│   └── SHOPPING_LIST.md   ← what to buy and when
├── configs/               ← build-specific configuration files
│   └── (inference.yaml, pin_map.yaml — TBD)
└── docs/
    ├── TOPOLOGY.md        ← network + compute layout
    └── (WIRING.md, CHASSIS.md — coming)
```

## Status

**Phase 1: Foundation** — Pi configured, SSH working, project structured. Next: chassis design, wiring, software scaffold.

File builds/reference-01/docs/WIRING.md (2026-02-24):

# EvoBot reference-01 Wiring Guide

**Build:** reference-01
**Date:** 2026-02-24
**Author:** Claude (architect), Scott Whitney (builder)
**Status:** REFERENCE DOCUMENT -- wire to this spec

---

## Table of Contents

1. [System Overview](#1-system-overview)
2. [Wire Color Conventions](#2-wire-color-conventions)
3. [Power Distribution](#3-power-distribution)
4. [Raspberry Pi 3B GPIO Pin Assignment](#4-raspberry-pi-3b-gpio-pin-assignment)
5. [ESP32 Pin Assignment](#5-esp32-pin-assignment)
6. [UART Serial Link (Pi to ESP32)](#6-uart-serial-link-pi-to-esp32)
7. [I2C Bus Layout](#7-i2c-bus-layout)
8. [Motor Driver Wiring (L293D Shield)](#8-motor-driver-wiring-l293d-shield)
9. [TT Motor and Encoder Wiring](#9-tt-motor-and-encoder-wiring)
10. [HC-SR04 Ultrasonic Sensor Wiring](#10-hc-sr04-ultrasonic-sensor-wiring)
11. [MPU6050 IMU Wiring](#11-mpu6050-imu-wiring)
12. [USB Webcam](#12-usb-webcam)
13. [Level Shifter Wiring](#13-level-shifter-wiring)
14. [Physical Kill Switch](#14-physical-kill-switch)
15. [Safety Watchdog Design (Constitution Art. 14)](#15-safety-watchdog-design-constitution-art-14)
16. [Complete System Wiring Diagram](#16-complete-system-wiring-diagram)
17. [Safety Notes and Current Budget](#17-safety-notes-and-current-budget)
18. [Pre-Power Checklist](#18-pre-power-checklist)

---

## 1. System Overview

```
┌─────────────────────────────────────────────────────────────────────────┐
│                        EvoBot reference-01                              │
│                                                                         │
│   2S Li-Ion (7.4V) ──[KILL SWITCH]──┬── L293D Motor Driver (direct)    │
│                                      │                                  │
│                                      └── Buck Converter ── 5V Rail      │
│                                                             │           │
│                                          ┌──────────────────┼─────┐     │
│                                          │                  │     │     │
│                                     [Pi 3B]           [ESP32]  [Sensors]│
│                                       │  │               │              │
│                                    [I2C] [USB]       [UART]            │
│                                       │    │           │                │
│                                   [MPU6050][Webcam] [L293D]            │
│                                                        │                │
│                                                   [TT Motors x2]       │
└─────────────────────────────────────────────────────────────────────────┘
```

**Signal flow:** Pi (brain) sends commands over UART serial to ESP32 (motor controller). ESP32 generates PWM, reads encoders, runs PID loop, and drives motors through L293D. Pi reads IMU over I2C and ultrasonic sensors through level-shifted GPIO. Webcam feeds directly to Pi over USB.

---

## 2. Wire Color Conventions

Use these colors consistently throughout the build. Label wires at both ends with tape or heat-shrink markers when colors are unavailable.

| Color | Function | Notes |
|---|---|---|
| **Red** | Power positive (any voltage) | Battery+, 5V, 3.3V -- label which |
| **Black** | Ground (GND) | ALL grounds tied together (common ground) |
| **Orange** | Battery voltage (7.4V raw) | From kill switch to buck converter and motor driver |
| **Yellow** | 5V regulated rail | Buck converter output to Pi, ESP32, sensors |
| **White** | UART TX lines | Pi TX, ESP32 TX |
| **Green** | UART RX lines | Pi RX, ESP32 RX |
| **Blue** | I2C SDA | Data line |
| **Purple/Violet** | I2C SCL | Clock line |
| **Grey** | Encoder signals | Encoder A and B channels |
| **Brown** | Motor power leads | Motor + and - to driver outputs |
| **Pink** | Ultrasonic trigger | HC-SR04 TRIG pins |
| **Tan/Beige** | Ultrasonic echo (level-shifted) | HC-SR04 ECHO through level shifter |

**Rule:** Every ground wire is black. No exceptions. If you run out of colored wire, use black with colored heat-shrink on the ends as labels.

---

## 3. Power Distribution

### 3.1 Power Architecture Diagram

```
                         ┌──────────────────────────────────────────────┐
                         │            POWER DISTRIBUTION                │
                         │                                              │
  ┌──────────┐    ┌──────┴──────┐                                       │
  │ 2S Li-Ion│    │ KILL SWITCH │                                       │
  │  7.4V    │────│ (SPST toggle│                                       │
  │  pack    │    │  on battery │                                       │
  └──────────┘    │  positive)  │                                       │
                  └──────┬──────┘                                       │
                         │                                              │
                    7.4V RAW BUS (orange wire)                          │
                         │                                              │
              ┌──────────┼──────────┐                                   │
              │                     │                                   │
     ┌────────┴────────┐   ┌───────┴────────┐                          │
     │  Buck Converter  │   │  L293D Motor   │                          │
     │  IN: 7.4V        │   │  Driver        │                          │
     │  OUT: 5.0V, 3A   │   │  VS (motor     │                          │
     │  (adjust pot     │   │  supply): 7.4V │                          │
     │   BEFORE wiring) │   │  VSS (logic):  │                          │
     └────────┬─────────┘   │  5V from rail  │                          │
              │              └────────────────┘                          │
         5V RAIL (yellow wire)                                          │
              │                                                         │
    ┌─────────┼─────────┬──────────┬──────────┐                         │
    │         │         │          │          │                          │
┌───┴───┐ ┌──┴───┐ ┌───┴───┐ ┌───┴────┐ ┌──┴──────────┐              │
│Pi 3B  │ │ESP32 │ │HC-SR04│ │HC-SR04 │ │Level Shifter│              │
│via    │ │VIN   │ │VCC x2 │ │VCC x2  │ │HV side      │              │
│micro  │ │pin   │ │(5V)   │ │(5V)    │ │(5V)         │              │
│USB    │ │(5V)  │ │       │ │        │ │             │              │
└───────┘ └──────┘ └───────┘ └────────┘ └─────────────┘              │
                                                                       │
                  3.3V RAIL (from Pi 3.3V pin and ESP32 3.3V pin)      │
                         │                                              │
              ┌──────────┼──────────┐                                   │
              │                     │                                   │
         ┌────┴────┐         ┌─────┴─────┐                             │
         │MPU6050  │         │Level      │                             │
         │VCC      │         │Shifter    │                             │
         │(3.3V)   │         │LV side    │                             │
         └─────────┘         └───────────┘                             │
                                                                       │
                  GND BUS (black wire -- ALL devices share)            │
                         │                                              │
    ┌────┬────┬────┬─────┼─────┬──────┬───────┬──────────┐            │
    │    │    │    │     │     │      │       │          │            │
   Pi  ESP32 L293D Buck  Batt- HC-SR04 HC-SR04 MPU6050  Lvl Shift   │
   GND  GND  GND  GND   GND   GND(L) GND(R)  GND      GND         │
                                                                       │
└──────────────────────────────────────────────────────────────────────┘
```

### 3.2 Power Rail Summary

| Rail | Voltage | Source | Max Current | Consumers |
|---|---|---|---|---|
| Battery raw | 7.4V nominal (6.0V-8.4V) | 2S Li-Ion pack | Depends on cells (typically 2-5A continuous) | Buck converter input, L293D VS (motor supply) |
| 5V regulated | 5.0V | Buck converter output | 3A (use a 3A+ rated buck) | Pi 3B (2.5A max), ESP32 VIN, HC-SR04 VCC x2, level shifter HV |
| 3.3V | 3.3V | Pi onboard regulator / ESP32 onboard regulator | ~50mA available from Pi pin 1 | MPU6050, level shifter LV side |

### 3.3 Critical Power Notes

1. **Measure buck converter output BEFORE connecting anything.** Adjust the pot to read 5.00-5.10V on a multimeter. Connecting a Pi to 7.4V will destroy it instantly.
2. **Pi power via micro-USB.** Cut a micro-USB cable, connect the red wire to 5V rail and black to GND. Or use a dedicated 5V micro-USB breakout. Do NOT power the Pi through GPIO pin 2 (5V) -- this bypasses the polyfuse and offers no protection.
3. **ESP32 power via VIN pin** (not the 3.3V pin). The VIN pin feeds the ESP32's onboard regulator. Acceptable input: 5V from the buck converter.
4. **Common ground is mandatory.** Every device on the robot must share the same ground bus. Float a ground and signals will not work, or worse, magic smoke escapes.

---

## 4. Raspberry Pi 3B GPIO Pin Assignment

The Pi 3B has a 40-pin GPIO header. Physical pin numbers count from the top-left (pin 1 = 3.3V, near the board edge). BCM numbers are the GPIO numbers used in software.

### 4.1 Complete Pin Map (40-pin header)

```
                    Pi 3B GPIO Header (top view, USB ports at bottom)
                    ┌─────────────────────────────────┐
                    │  oooooooooooooooooooo            │
                    │  oooooooooooooooooooo            │
                    │  Pin 1 (3V3)  Pin 2 (5V)        │
                    └─────────────────────────────────┘

     Pin 1 side (odd)          Pin 2 side (even)
    ┌──────────────────────┬──────────────────────┐
    │ Phys │ BCM  │ Func   │ Func   │ BCM  │ Phys │
    ├──────┼──────┼────────┼────────┼──────┼──────┤
    │   1  │ —    │ 3V3    │ 5V     │ —    │   2  │
    │   3  │ GP2  │ I2C SDA│ 5V     │ —    │   4  │
    │   5  │ GP3  │ I2C SCL│ GND    │ —    │   6  │
    │   7  │ GP4  │ —      │ UART TX│ GP14 │   8  │
    │   9  │ —    │ GND    │ UART RX│ GP15 │  10  │
    │  11  │ GP17 │ —      │ —      │ GP18 │  12  │
    │  13  │ GP27 │ —      │ GND    │ —    │  14  │
    │  15  │ GP22 │ —      │ —      │ GP23 │  16  │
    │  17  │ —    │ 3V3    │ —      │ GP24 │  18  │
    │  19  │ GP10 │ SPI MO │ GND    │ —    │  20  │
    │  21  │ GP9  │ SPI MI │ —      │ GP25 │  22  │
    │  23  │ GP11 │ SPI CLK│ SPI CE0│ GP8  │  24  │
    │  25  │ —    │ GND    │ SPI CE1│ GP7  │  26  │
    │  27  │ GP0  │ ID SD  │ ID SC  │ GP1  │  28  │
    │  29  │ GP5  │ —      │ GND    │ —    │  30  │
    │  31  │ GP6  │ —      │ —      │ GP12 │  32  │
    │  33  │ GP13 │ —      │ GND    │ —    │  34  │
    │  35  │ GP19 │ —      │ —      │ GP16 │  36  │
    │  37  │ GP26 │ —      │ —      │ GP20 │  38  │
    │  39  │ —    │ GND    │ —      │ GP21 │  40  │
    └──────┴──────┴────────┴────────┴──────┴──────┘
```

### 4.2 Pi GPIO Assignments for EvoBot reference-01

| Physical Pin | BCM GPIO | Direction | Connected To | Wire Color | Notes |
|---|---|---|---|---|---|
| 1 | -- | PWR | 3.3V rail out | Red (labeled 3V3) | Powers MPU6050, level shifter LV |
| 2 | -- | PWR | 5V (from USB) | -- | Do NOT use as power input |
| 3 | GPIO2 | I/O | MPU6050 SDA | Blue | I2C1 SDA (hardware I2C) |
| 4 | -- | PWR | 5V | -- | Not connected |
| 5 | GPIO3 | I/O | MPU6050 SCL | Purple | I2C1 SCL (hardware I2C) |
| 6 | -- | GND | Ground bus | Black | Primary GND tie point |
| 8 | GPIO14 | OUT | ESP32 RX (GPIO16) | White | Pi UART TX -> ESP32 RX |
| 9 | -- | GND | Ground bus | Black | |
| 10 | GPIO15 | IN | ESP32 TX (GPIO17) | Green | Pi UART RX <- ESP32 TX |
| 11 | GPIO17 | IN | HC-SR04 LEFT Echo (via level shifter) | Tan | 3.3V level-shifted echo |
| 13 | GPIO27 | IN | HC-SR04 RIGHT Echo (via level shifter) | Tan | 3.3V level-shifted echo |
| 15 | GPIO22 | OUT | HC-SR04 LEFT Trigger | Pink | 3.3V out, HC-SR04 accepts 3.3V trigger |
| 16 | GPIO23 | OUT | HC-SR04 RIGHT Trigger | Pink | 3.3V out, HC-SR04 accepts 3.3V trigger |
| 14 | -- | GND | Ground bus | Black | |
| 17 | -- | PWR | 3.3V | -- | Alternate 3.3V source (spare) |
| 20 | -- | GND | Ground bus | Black | |
| 25 | -- | GND | Ground bus | Black | |
| 30 | -- | GND | Ground bus | Black | |
| 34 | -- | GND | Ground bus | Black | |
| 39 | -- | GND | Ground bus | Black | |

**Pins NOT used (reserved/available for future expansion):**

| Physical Pin | BCM GPIO | Reserved For |
|---|---|---|
| 7 | GPIO4 | Future: 1-Wire bus (temp sensors) |
| 12 | GPIO18 | Future: PWM output (buzzer, LED) |
| 18 | GPIO24 | Future: additional sensor |
| 19 | GPIO10 | SPI MOSI (reserved for SPI devices) |
| 21 | GPIO9 | SPI MISO (reserved for SPI devices) |
| 22 | GPIO25 | Future: status LED |
| 23 | GPIO11 | SPI SCLK (reserved for SPI devices) |
| 24 | GPIO8 | SPI CE0 (reserved for SPI devices) |
| 26 | GPIO7 | SPI CE1 (reserved for SPI devices) |
| 27 | GPIO0 | EEPROM ID (do not use) |
| 28 | GPIO1 | EEPROM ID (do not use) |
| 29 | GPIO5 | Future: additional sensor/interrupt |
| 31 | GPIO6 | Future: additional sensor/interrupt |
| 32 | GPIO12 | Future: PWM output |
| 33 | GPIO13 | Future: PWM output |
| 35 | GPIO19 | Future: additional I/O |
| 36 | GPIO16 | Future: additional I/O |
| 37 | GPIO26 | Future: additional I/O |
| 38 | GPIO20 | Future: additional I/O |
| 40 | GPIO21 | Future: additional I/O |

### 4.3 Pi UART Configuration

The Pi 3B maps the hardware UART (PL011) to Bluetooth by default. For reliable serial communication with the ESP32, you must swap this:

```bash
# Add to /boot/config.txt (or /boot/firmware/config.txt on Bookworm):
dtoverlay=disable-bt

# Disable the Bluetooth modem service:
sudo systemctl disable hciuart

# Reboot. After reboot:
# /dev/ttyAMA0 = PL011 UART on GPIO14/GPIO15 (reliable, no jitter)
# Bluetooth is disabled (acceptable -- Pi uses WiFi for networking)
```

**If you need Bluetooth AND serial:** use `dtoverlay=miniuart-bt` instead, which puts the mini UART on Bluetooth and PL011 on GPIO. But the mini UART's baud rate drifts with CPU clock. Disabling BT entirely is cleaner for v1.

---

## 5. ESP32 Pin Assignment

Standard ESP32 DevKit v1 (30-pin or 38-pin). Pin labels vary by manufacturer -- verify against YOUR specific board's silkscreen. The GPIO numbers below are universal across ESP32 WROOM-32 modules.

### 5.1 ESP32 Pin Map for EvoBot reference-01

| ESP32 GPIO | Direction | Connected To | Wire Color | Notes |
|---|---|---|---|---|
| **GPIO16** | IN (RX) | Pi GPIO14 TX (phys pin 8) | White | UART2 RX -- receives commands from Pi |
| **GPIO17** | OUT (TX) | Pi GPIO15 RX (phys pin 10) | Green | UART2 TX -- sends data to Pi |
| **GPIO25** | OUT | L293D IN1 (Motor A input 1) | -- | Motor A direction pin 1 |
| **GPIO26** | OUT | L293D IN2 (Motor A input 2) | -- | Motor A direction pin 2 |
| **GPIO27** | OUT | L293D IN3 (Motor B input 1) | -- | Motor B direction pin 1 |
| **GPIO14** | OUT | L293D IN4 (Motor B input 2) | -- | Motor B direction pin 2 |
| **GPIO32** | OUT (PWM) | L293D ENA (Motor A enable/speed) | -- | LEDC PWM channel 0, 20 kHz |
| **GPIO33** | OUT (PWM) | L293D ENB (Motor B enable/speed) | -- | LEDC PWM channel 1, 20 kHz |
| **GPIO34** | IN | Left motor encoder channel A | Grey | Input-only pin (no pullup, add external 10k to 3.3V) |
| **GPIO35** | IN | Left motor encoder channel B | Grey | Input-only pin (no pullup, add external 10k to 3.3V) |
| **GPIO36** (VP) | IN | Right motor encoder channel A | Grey | Input-only pin (no pullup, add external 10k to 3.3V) |
| **GPIO39** (VN) | IN | Right motor encoder channel B | Grey | Input-only pin (no pullup, add external 10k to 3.3V) |
| **GPIO4** | OUT | Heartbeat watchdog timeout -> motor kill | -- | Goes LOW to disable L293D enable pins (see Section 15) |
| **VIN** | PWR IN | 5V rail (from buck converter) | Yellow | Powers ESP32 via onboard regulator |
| **3V3** | PWR OUT | Level shifter LV reference (if needed) | Red (labeled 3V3) | 3.3V output from ESP32 regulator |
| **GND** | GND | Ground bus | Black | Common ground |

### 5.2 ESP32 Pins to Avoid

| GPIO | Reason |
|---|---|
| GPIO0 | Boot mode select -- pulled LOW enters flash mode. Do not use for general I/O. |
| GPIO1 | UART0 TX (USB serial debug console). Leave for debug output. |
| GPIO2 | Boot mode related, connected to onboard LED on most DevKits. Avoid for critical I/O. |
| GPIO3 | UART0 RX (USB serial debug console). Leave for debug input. |
| GPIO5 | Strapping pin (SPI SS). May cause boot issues if pulled LOW at startup. |
| GPIO6-11 | Connected to internal SPI flash. NEVER use these. |
| GPIO12 | Strapping pin (MTDI). If HIGH at boot, flash voltage set wrong -> boot failure. |
| GPIO15 | Strapping pin (MTDO). Pulling LOW suppresses boot log. Usable but be cautious. |

### 5.3 ESP32 PWM Configuration

```
Motor A (Left):  LEDC Channel 0, GPIO32, 20 kHz, 8-bit resolution (0-255)
Motor B (Right): LEDC Channel 1, GPIO33, 20 kHz, 8-bit resolution (0-255)

20 kHz is above human hearing -- no motor whine.
8-bit gives 256 speed steps -- adequate for TT motors.
```

---

## 6. UART Serial Link (Pi to ESP32)

### 6.1 Physical Connection

```
     Pi 3B                              ESP32
    ┌──────────┐                      ┌──────────┐
    │ GPIO14   │──── White wire ─────→│ GPIO16   │
    │ (TX)     │     (Pi TX -> ESP RX)│ (RX2)    │
    │ Pin 8    │                      │          │
    │          │                      │          │
    │ GPIO15   │←─── Green wire ──────│ GPIO17   │
    │ (RX)     │     (ESP TX -> Pi RX)│ (TX2)    │
    │ Pin 10   │                      │          │
    │          │                      │          │
    │ GND      │──── Black wire ──────│ GND      │
    │ Pin 6    │     (common ground)  │          │
    └──────────┘                      └──────────┘
```

**NO level shifter needed.** Both Pi GPIO and ESP32 GPIO operate at 3.3V logic levels.

### 6.2 Serial Protocol Specification

| Parameter | Value |
|---|---|
| Baud rate | **115200** |
| Data bits | 8 |
| Parity | None |
| Stop bits | 1 |
| Flow control | None |
| Logic level | 3.3V (both sides) |
| Pi device | `/dev/ttyAMA0` (after `dtoverlay=disable-bt`) |
| ESP32 UART | UART2 (GPIO16 RX, GPIO17 TX) |
| Encoding | ASCII text, newline-terminated (`\n`) |

### 6.3 Command Protocol (Pi -> ESP32)

Commands are ASCII strings terminated by newline (`\n`). Simple, human-readable, debuggable with a serial terminal.

| Command | Format | Example | Description |
|---|---|---|---|
| Set motor speeds | `M <left> <right>\n` | `M 150 150\n` | Set PWM: -255 to +255 (negative = reverse) |
| Stop all motors | `S\n` | `S\n` | Immediate stop (both motors to 0) |
| Query encoders | `E?\n` | `E?\n` | Request encoder counts |
| Heartbeat | `H\n` | `H\n` | Watchdog keep-alive (must send every 500ms) |
| Set PID params | `P <Kp> <Ki> <Kd>\n` | `P 1.0 0.1 0.05\n` | Update PID tuning (applies to both motors) |

### 6.4 Response Protocol (ESP32 -> Pi)

| Response | Format | Example | Description |
|---|---|---|---|
| Encoder counts | `E <left> <right>\n` | `E 1024 1019\n` | Cumulative encoder ticks since boot |
| Acknowledgment | `OK\n` | `OK\n` | Command received and executed |
| Error | `ERR <msg>\n` | `ERR BAD_CMD\n` | Command not recognized or invalid |
| Watchdog timeout | `WDT\n` | `WDT\n` | Heartbeat missed, motors killed |

### 6.5 Heartbeat Watchdog Timing

| Parameter | Value |
|---|---|
| Heartbeat interval (Pi sends) | Every **250ms** (4 Hz) |
| Watchdog timeout (ESP32 triggers) | **1000ms** (1 second without heartbeat) |
| Action on timeout | ESP32 sets both motor PWMs to 0, sends `WDT\n` |
| Recovery | Pi resumes sending `H\n`, ESP32 re-enables motor commands |

This implements **Constitution Article 14.3**: "When communication is lost, return to safe state." The ESP32 does not need the Pi's permission to stop the motors. If the Pi crashes, hangs, or loses serial connection, the motors stop within 1 second. The ESP32 is the independent safety layer.

---

## 7. I2C Bus Layout

### 7.1 Bus Configuration

| Parameter | Value |
|---|---|
| Bus | I2C1 (hardware I2C on Pi 3B) |
| SDA | GPIO2 (physical pin 3) |
| SCL | GPIO3 (physical pin 5) |
| Bus voltage | 3.3V |
| Bus speed | 100 kHz (standard mode) |
| Pull-up resistors | **4.7k ohm** to 3.3V on both SDA and SCL |

### 7.2 I2C Device Table

| Device | I2C Address | Voltage | Notes |
|---|---|---|---|
| MPU6050 IMU | **0x68** (AD0 pin LOW or floating) | 3.3V native | Alt address: 0x69 if AD0 pulled HIGH |

### 7.3 Pull-Up Resistor Placement

The MPU6050 breakout board typically has onboard 4.7k pull-ups to VCC. **Verify this on your specific board** by checking for resistors near the SDA/SCL pins (often labeled R1, R2 or marked 472).

- **If your MPU6050 board has pull-ups:** No additional resistors needed.
- **If your MPU6050 board lacks pull-ups:** Add 4.7k resistors from SDA to 3.3V and from SCL to 3.3V on a breadboard.
- **Never double up pull-ups** (board + external). Too-strong pull-ups can cause communication errors.

### 7.4 I2C Wiring Diagram

```
     Pi 3B                              MPU6050
    ┌──────────┐                      ┌──────────┐
    │ Pin 1    │─── Red ─────────────→│ VCC      │  (3.3V)
    │ (3V3)    │                      │          │
    │          │                      │          │
    │ Pin 3    │─── Blue ────────────→│ SDA      │
    │ (GPIO2)  │                      │          │
    │          │                      │          │
    │ Pin 5    │─── Purple ──────────→│ SCL      │
    │ (GPIO3)  │                      │          │
    │          │                      │          │
    │ Pin 6    │─── Black ───────────→│ GND      │
    │ (GND)    │                      │          │
    │          │                      │ AD0      │──→ Leave floating or tie to GND (addr 0x68)
    │          │                      │ INT      │──→ Not connected in v1 (future: Pi GPIO for interrupt)
    └──────────┘                      └──────────┘

    Pull-ups (if not on MPU6050 board):
    SDA (Blue) ──── 4.7k ──── 3.3V (Red)
    SCL (Purple) ── 4.7k ──── 3.3V (Red)
```

### 7.5 I2C Verification

After wiring, before running any code:

```bash
# On the Pi, scan I2C bus 1:
sudo apt install i2c-tools    # if not already installed
i2cdetect -y 1

# Expected output: device at address 0x68
#      0  1  2  3  4  5  6  7  8  9  a  b  c  d  e  f
# 60: -- -- -- -- -- -- -- -- 68 -- -- -- -- -- -- --
```

If `0x68` does not appear: check wiring, check pull-ups, check that I2C is enabled in `raspi-config`.

---

## 8. Motor Driver Wiring (L293D Shield)

### 8.1 About the L293D

The Arduino Motor Shield (L293D-based) provides two H-bridge channels (Motor A and Motor B), each capable of driving a DC motor bidirectionally. In this build, the shield is used as a standalone breakout -- it is NOT plugged into an Arduino. The ESP32 drives its control pins directly.

**If using a standalone L293D chip** instead of the shield, the pinout differs. This section covers BOTH options.

### 8.2 Option A: Arduino L293D Motor Shield (as breakout)

The shield has screw terminals for motors and a separate power input for motor voltage. The control pins are exposed on the Arduino-format headers.

| Shield Pin | Function | Connected To |
|---|---|---|
| Motor A terminal (+/-) | Motor A output | Left TT motor wires |
| Motor B terminal (+/-) | Motor B output | Right TT motor wires |
| EXT_PWR (+) | Motor supply voltage | 7.4V battery raw (orange wire) |
| EXT_PWR (-) | Motor supply ground | Ground bus (black wire) |
| EXT_PWR jumper | Cut or remove if present | Isolates Arduino 5V from motor voltage |

**Shield control pins (directly map to Arduino digital pins):**

| Arduino Pin Label | Shield Function | ESP32 GPIO |
|---|---|---|
| D12 | Direction A (IN1 equivalent) | GPIO25 |
| D13 | Direction A (IN2 equivalent) | GPIO26 |
| D8 | Direction B (IN3 equivalent) | GPIO27 |
| D11 | Direction B (IN4 equivalent) | GPIO14 |
| D3 | Enable A (ENA / PWM speed) | GPIO32 |
| D9 or D11 | Enable B (ENB / PWM speed) | GPIO33 |

**Important:** Different L293D shield clones have different pin mappings. The Adafruit Motor Shield v1 uses D4, D7, D8, D12 for direction and D3, D11 for PWM. Check YOUR shield's schematic. If in doubt, use a multimeter in continuity mode to trace which header pin connects to which L293D chip pin.

**Power jumper:** Most shields have a jumper connecting the motor power to Arduino VIN. **Remove this jumper.** You do not want 7.4V feeding back to the ESP32. The shield's logic power comes from the 5V rail through separate wiring.

### 8.3 Option B: Standalone L293D Chip (DIP-16)

If using a bare L293D on a breadboard instead of a shield:

```
              L293D (DIP-16, top view)
           ┌────────┐
  ENA  1 ──┤        ├── 16  VSS (logic 5V)
  IN1  2 ──┤        ├── 15  IN4
  OUT1 3 ──┤        ├── 14  OUT4
  GND  4 ──┤ L293D  ├── 13  GND
  GND  5 ──┤        ├── 12  GND
  OUT2 6 ──┤        ├── 11  OUT3
  IN2  7 ──┤        ├── 10  IN3
  VS   8 ──┤        ├──  9  ENB
           └────────┘
```

| L293D Pin | Name | Connected To |
|---|---|---|
| 1 | ENA (Enable A) | ESP32 GPIO32 (PWM) |
| 2 | IN1 | ESP32 GPIO25 |
| 3 | OUT1 | Left motor wire 1 (brown) |
| 4, 5, 12, 13 | GND (all four) | Ground bus (black). Solder/connect ALL four GND pins -- they are heat sinks. |
| 6 | OUT2 | Left motor wire 2 (brown) |
| 7 | IN2 | ESP32 GPIO26 |
| 8 | VS (motor supply) | 7.4V battery raw (orange wire) |
| 9 | ENB (Enable B) | ESP32 GPIO33 (PWM) |
| 10 | IN3 | ESP32 GPIO27 |
| 11 | OUT3 | Right motor wire 1 (brown) |
| 14 | OUT4 | Right motor wire 2 (brown) |
| 15 | IN4 | ESP32 GPIO14 |
| 16 | VSS (logic supply) | 5V rail (yellow wire) |

### 8.4 Motor Direction Truth Table

| IN1 | IN2 | Motor A Behavior |
|---|---|---|
| HIGH | LOW | Forward |
| LOW | HIGH | Reverse |
| LOW | LOW | Coast (free spin) |
| HIGH | HIGH | Brake (short circuit) |

Same logic applies to IN3/IN4 for Motor B. ENA/ENB PWM controls speed (0 = stopped, 255 = full speed).

**Note:** "Forward" and "reverse" depend on motor wiring polarity. If a motor spins the wrong way, swap its two output wires (OUT1/OUT2 or OUT3/OUT4) rather than changing code.

---

## 9. TT Motor and Encoder Wiring

### 9.1 TT Motor Connections

Each TT geared DC motor has two power wires (motor+ and motor-). These connect to the L293D output terminals.

| Motor | L293D Output | Notes |
|---|---|---|
| Left motor wire 1 | OUT1 (pin 3) | |
| Left motor wire 2 | OUT2 (pin 6) | If motor spins wrong direction, swap these two wires |
| Right motor wire 1 | OUT3 (pin 11) | |
| Right motor wire 2 | OUT4 (pin 14) | If motor spins wrong direction, swap these two wires |

### 9.2 Encoder Connections

The TT motor encoders (if your motors have them -- the yellow TT motors with the encoder disk on the back) typically have 4 pins:

| Encoder Pin | Label | Connected To | Wire Color |
|---|---|---|---|
| VCC | + / VCC | 3.3V (from ESP32 3V3 pin or Pi pin 1) | Red |
| GND | - / GND | Ground bus | Black |
| Channel A | OUT A / C1 | See table below | Grey |
| Channel B | OUT B / C2 | See table below | Grey |

**Encoder signal connections to ESP32:**

| Signal | ESP32 GPIO | Notes |
|---|---|---|
| Left encoder channel A | GPIO34 | Input-only. Add 10k pull-up to 3.3V. |
| Left encoder channel B | GPIO35 | Input-only. Add 10k pull-up to 3.3V. |
| Right encoder channel A | GPIO36 (VP) | Input-only. Add 10k pull-up to 3.3V. |
| Right encoder channel B | GPIO39 (VN) | Input-only. Add 10k pull-up to 3.3V. |

### 9.3 Encoder Pull-Up Resistors

ESP32 GPIO34, 35, 36, 39 are input-only pins with NO internal pull-up capability. You MUST add external pull-up resistors:

```
    3.3V ─── 10k ──┬── Encoder Channel A ──→ ESP32 GPIO34
                    │
              (encoder output drives this line)

    Repeat for GPIO35, GPIO36, GPIO39.
```

Place these four 10k resistors on the mini breadboard near the ESP32.

### 9.4 Encoder Notes

- TT motor encoders are typically 20 slots per revolution of the encoder disk. With the gear ratio (~1:48), this gives approximately 960 edges per wheel revolution (with quadrature decoding).
- Encoder output is open-collector or push-pull depending on the specific module. The pull-ups ensure a clean HIGH when no pulse is active.
- The ESP32 handles encoder counting via hardware interrupts (PCNT peripheral or ISR) -- this is why encoder signals go to the ESP32, not the Pi. Linux cannot reliably count pulses at motor speed.

---

## 10. HC-SR04 Ultrasonic Sensor Wiring

### 10.1 HC-SR04 Overview

The HC-SR04 requires 5V power and outputs a 5V echo pulse. The Pi GPIO is 3.3V and is NOT 5V tolerant. The echo pin MUST be level-shifted before connecting to the Pi.

| HC-SR04 Pin | Voltage | Notes |
|---|---|---|
| VCC | 5V | Power supply |
| GND | GND | Ground |
| TRIG | Accepts 3.3V or 5V | Pi 3.3V output is sufficient to trigger |
| ECHO | Outputs 5V | MUST level-shift to 3.3V before Pi GPIO |

### 10.2 Ultrasonic Sensor Placement

| Sensor | Position | Purpose |
|---|---|---|
| HC-SR04 LEFT | Front-left, angled ~30 degrees outward | Left obstacle detection |
| HC-SR04 RIGHT | Front-right, angled ~30 degrees outward | Right obstacle detection |

### 10.3 Wiring (Both Sensors)

```
                                    Level Shifter
    Pi 3B                          (3.3V <-> 5V)              HC-SR04 LEFT
   ┌──────────┐                   ┌─────────────┐            ┌──────────┐
   │ Pin 1    │─── Red ─────────→│ LV (3.3V)   │            │          │
   │ (3V3)    │                   │             │            │          │
   │          │                   │ HV (5V) ────│── Yellow ──│→ VCC     │
   │          │     5V Rail ─────→│             │            │          │
   │          │                   │             │            │          │
   │ GPIO22   │─── Pink ─────────────────────────────────────│→ TRIG    │
   │ (Pin 15) │   (direct, 3.3V is fine for trigger)        │          │
   │          │                   │             │            │          │
   │ GPIO17   │←── Tan ──────────│← LV1    HV1─│←── Tan ───│← ECHO    │
   │ (Pin 11) │   (3.3V shifted) │             │  (5V raw)  │          │
   │          │                   │             │            │          │
   │ GND      │─── Black ───────→│ GND ────────│── Black ──→│ GND      │
   │ (Pin 6)  │                   │             │            │          │
   └──────────┘                   └─────────────┘            └──────────┘

    Pi 3B                          Level Shifter              HC-SR04 RIGHT
   ┌──────────┐                   (same module,             ┌──────────┐
   │          │                    channel 2)                │          │
   │          │                   ┌─────────────┐            │          │
   │          │     5V Rail ─────→│ HV (shared) │── Yellow ──│→ VCC     │
   │          │                   │             │            │          │
   │ GPIO23   │─── Pink ─────────────────────────────────────│→ TRIG    │
   │ (Pin 16) │   (direct, 3.3V trigger)                    │          │
   │          │                   │             │            │          │
   │ GPIO27   │←── Tan ──────────│← LV2    HV2─│←── Tan ───│← ECHO    │
   │ (Pin 13) │   (3.3V shifted) │             │  (5V raw)  │          │
   │          │                   │             │            │          │
   │ GND      │─── Black ───────→│ GND ────────│── Black ──→│ GND      │
   └──────────┘                   └─────────────┘            └──────────┘
```

### 10.4 Trigger Pin Note

The HC-SR04 trigger input threshold is typically ~2.0V. The Pi GPIO outputs 3.3V when HIGH, which exceeds this threshold reliably. No level shifting is needed on the trigger pin -- only on the echo pin.

### 10.5 Timing

- Trigger pulse: 10 microsecond HIGH pulse
- Echo pulse width: proportional to distance (58 us per cm, round-trip)
- Minimum reading interval: 60ms between triggers (to avoid echo cross-talk between the two sensors)
- Stagger the left and right sensor triggers by 30ms

---

## 11. MPU6050 IMU Wiring

See Section 7 (I2C Bus Layout) for complete wiring details.

### 11.1 Connection Summary

| MPU6050 Pin | Connected To | Wire Color |
|---|---|---|
| VCC | Pi pin 1 (3.3V) | Red |
| GND | Pi pin 6 (GND) | Black |
| SDA | Pi pin 3 (GPIO2) | Blue |
| SCL | Pi pin 5 (GPIO3) | Purple |
| AD0 | GND or floating | -- (sets address to 0x68) |
| INT | Not connected (v1) | -- (future: Pi GPIO for data-ready interrupt) |
| XDA | Not connected | -- (auxiliary I2C master, unused) |
| XCL | Not connected | -- (auxiliary I2C master, unused) |

### 11.2 MPU6050 Provides

| Data | Resolution | Update Rate |
|---|---|---|
| 3-axis accelerometer | 16-bit, +/- 2g (configurable to +/-16g) | Up to 1 kHz |
| 3-axis gyroscope | 16-bit, +/- 250 deg/s (configurable to +/-2000 deg/s) | Up to 1 kHz |
| Temperature | Built-in | With each sample |

For v1, read at 100 Hz. This is more than sufficient for tilt detection and heading estimation on a slow-moving floor robot.

---

## 12. USB Webcam

| Connection | Details |
|---|---|
| Interface | USB 2.0 (Pi has 4x USB-A ports) |
| Power | Drawn from Pi USB port (max 600mA combined across all ports without powered hub) |
| Software | OpenCV (`cv2.VideoCapture(0)`) or `fswebcam` for still capture |
| Resolution | 640x480 recommended for Pi 3B (720p is possible but CPU-heavy) |

**No wiring diagram needed** -- plug into any Pi USB port. If the webcam draws too much current and causes Pi undervolt (lightning bolt icon on screen), use a powered USB hub or a lower-power webcam.

---

## 13. Level Shifter Wiring

### 13.1 Module Type

Use a bidirectional logic level converter module (commonly marked "Logic Level Converter" or "BSS138-based 4-channel"). These modules have:

- **LV** side: Low voltage reference (3.3V)
- **HV** side: High voltage reference (5V)
- **4 channels** (labeled 1-4 or A1-A4 / B1-B4): Each channel shifts one signal

### 13.2 Level Shifter Connections

| Module Pin | Connected To | Notes |
|---|---|---|
| LV | Pi pin 1 (3.3V) or Pi pin 17 (3.3V) | Low-voltage reference |
| HV | 5V rail | High-voltage reference |
| GND (LV side) | Ground bus | Common ground |
| GND (HV side) | Ground bus | Common ground |
| LV1 | Pi GPIO17 (pin 11) | Left echo, 3.3V side |
| HV1 | HC-SR04 LEFT Echo pin | Left echo, 5V side |
| LV2 | Pi GPIO27 (pin 13) | Right echo, 3.3V side |
| HV2 | HC-SR04 RIGHT Echo pin | Right echo, 5V side |
| LV3 | Not connected | Spare channel |
| LV4 | Not connected | Spare channel |
| HV3 | Not connected | Spare channel |
| HV4 | Not connected | Spare channel |

### 13.3 Alternative: Voltage Divider

If no level shifter module is available, a simple voltage divider on each echo pin works:

```
    HC-SR04 ECHO (5V) ──── 1k ohm ────┬──── Pi GPIO (3.3V safe)
                                        │
                                    2k ohm
                                        │
                                       GND

    Output = 5V * (2k / (1k + 2k)) = 3.33V
```

The level shifter module is preferred because it provides a cleaner signal and works bidirectionally. The voltage divider is one-way (5V to 3.3V only) but is adequate for the echo pin which only needs to be read by the Pi.

---

## 14. Physical Kill Switch

### 14.1 Purpose

Per **Constitution Article 14** (Fail-Safe Defaults): The robot must have an immediately accessible physical means to cut all power. No software, no wireless, no delays. A human hand on a switch kills everything.

### 14.2 Switch Specification

| Parameter | Value |
|---|---|
| Type | SPST toggle switch (ON/OFF) |
| Current rating | Minimum 5A (10A preferred) |
| Voltage rating | Minimum 12V DC |
| Mounting | Chassis top deck, clearly visible and accessible |
| Label | **"KILL"** or **"POWER"** -- clearly marked |

### 14.3 Wiring

```
    ┌──────────────┐
    │  2S Li-Ion    │
    │  Battery Pack │
    │               │
    │  (+) ────────────── RED wire ──────┐
    │               │                     │
    │  (-) ────────────── BLACK wire ──┐  │
    └──────────────┘                   │  │
                                       │  │
                                       │  │
                              ┌────────┴──┴─────────┐
                              │    KILL SWITCH       │
                              │    (SPST Toggle)     │
                              │                      │
                              │  Battery(+) ── IN    │
                              │  OUT ── System(+)    │
                              │                      │
                              │  (switch is on the   │
                              │   POSITIVE lead only) │
                              └──────────┬───────────┘
                                         │
                                    ORANGE wire
                                    (7.4V switched)
                                         │
                              ┌──────────┴──────────┐
                              │                     │
                         To Buck Conv          To L293D VS
                         (IN+)                 (motor supply)

    Battery(-) ── BLACK wire ──→ Ground bus (direct, no switch)
```

### 14.4 Switch Placement

- Mount on the **top deck** of the chassis where a human hand can reach it without bending down or reaching around.
- The switch should be **the most prominent feature** on the top deck -- not hidden among wires.
- Consider a **red** switch or red surround for visibility.
- Test the switch by flipping it OFF while motors are running. Everything should stop instantly. The Pi will lose power and shut down (not clean, but safe -- use a filesystem in read-only mode or accept the rare SD card corruption risk).

### 14.5 Optional: Separate Logic Power

For a cleaner shutdown, you can add a second switch (or use a DPST toggle) that cuts motor power on one pole and keeps logic power on the other. This allows the Pi to remain powered for clean shutdown while motors are killed. For v1, a single switch cutting everything is simpler and acceptable.

---

## 15. Safety Watchdog Design (Constitution Art. 14)

### 15.1 Principle

**Constitution Article 14.3:** "When communication is lost, return to safe state."

The ESP32 acts as an independent safety watchdog. If the Pi stops communicating (crash, hang, kernel panic, serial cable disconnected), the ESP32 kills motor power automatically. The ESP32 does not need the Pi's permission to stop the motors. This is the foundational fail-safe.

### 15.2 Watchdog State Machine

```
                         ┌─────────────────────┐
                         │   ESP32 BOOT         │
                         │   Motors: DISABLED    │
                         │   Waiting for first H │
                         └──────────┬────────────┘
                                    │
                              First 'H\n' received
                                    │
                                    v
                         ┌─────────────────────┐
                    ┌───→│   ACTIVE              │
                    │    │   Motors: ENABLED      │←─────────┐
                    │    │   Watchdog timer: reset│          │
                    │    └──────────┬────────────┘          │
                    │               │                        │
                    │         No 'H\n' for 1000ms           │
                    │               │                        │
                    │               v                        │
                    │    ┌─────────────────────┐             │
                    │    │   TIMED OUT          │             │
                    │    │   Motors: KILLED (0)  │             │
                    │    │   Sends 'WDT\n' to Pi│             │
                    │    └──────────┬────────────┘            │
                    │               │                        │
                    │         'H\n' received again           │
                    │               │                        │
                    └───────────────┘                        │
                              (recovery)
```

### 15.3 Implementation (ESP32 Pseudocode)

```cpp
unsigned long lastHeartbeat = 0;
bool motorsEnabled = false;
const unsigned long WATCHDOG_TIMEOUT_MS = 1000;

void loop() {
    // Check serial for commands
    if (Serial2.available()) {
        String cmd = Serial2.readStringUntil('\n');
        if (cmd == "H") {
            lastHeartbeat = millis();
            motorsEnabled = true;
        } else if (cmd == "S") {
            stopMotors();
        } else if (cmd.startsWith("M ")) {
            if (motorsEnabled) {
                parseAndSetMotors(cmd);
            }
        }
        // ... other commands
    }

    // WATCHDOG CHECK -- runs every loop iteration
    if (motorsEnabled && (millis() - lastHeartbeat > WATCHDOG_TIMEOUT_MS)) {
        stopMotors();
        motorsEnabled = false;
        Serial2.println("WDT");
    }

    // PID loop runs here at fixed interval
    runPID();
}
```

### 15.4 Fail-Safe Defaults Summary

| Condition | ESP32 Action | Motors |
|---|---|---|
| ESP32 just booted, no heartbeat received yet | Wait | DISABLED |
| Heartbeat arriving normally | Process commands | ENABLED |
| Heartbeat missed for > 1 second | Kill motors, send WDT | DISABLED |
| Heartbeat resumes after timeout | Re-enable commands | ENABLED |
| Invalid/corrupt command received | Ignore, send ERR | Unchanged |
| ESP32 itself crashes/resets | Boots into disabled state | DISABLED (safe default) |

**Every failure mode results in motors OFF.** This is the definition of fail-safe.

---

## 16. Complete System Wiring Diagram

### 16.1 Full ASCII Wiring Diagram

```
═══════════════════════════════════════════════════════════════════════════════
                     EvoBot reference-01 — COMPLETE WIRING
═══════════════════════════════════════════════════════════════════════════════

   ┌─────────────┐         ┌──────────────┐
   │ 2S Li-Ion   │         │  KILL SWITCH │
   │ Battery     │         │  (SPST)      │
   │ 7.4V        │         │              │
   │  (+)────────│─── RED──│─ IN     OUT ─│── ORANGE ──┬──────────────────────┐
   │  (-)────────│─ BLACK ─│──────────────│────────┐   │                      │
   └─────────────┘         └──────────────┘        │   │                      │
                                                   │   │                      │
                                              GND BUS  │  7.4V SWITCHED BUS   │
                                              (black)  │  (orange)            │
                                                   │   │                      │
                          ┌────────────────────────┤   │                      │
                          │                        │   │                      │
                   ┌──────┴──────┐          ┌──────┴───┴──────┐               │
                   │ BUCK CONV   │          │  L293D MOTOR    │               │
                   │ IN+: orange │          │  DRIVER         │               │
                   │ IN-: black  │          │                 │               │
                   │ OUT+: 5.0V  │          │  VS: orange     │               │
                   │ OUT-: black │          │  (7.4V motor    │               │
                   │             │          │   supply)       │               │
                   │ ADJUST POT  │          │  VSS: yellow    │               │
                   │ TO 5.00V    │          │  (5V logic)     │               │
                   │ BEFORE USE! │          │  GND: black     │               │
                   └──────┬──────┘          │                 │               │
                          │                 │  IN1: ESP GPIO25│               │
                     5V RAIL                │  IN2: ESP GPIO26│               │
                    (yellow)                │  IN3: ESP GPIO27│               │
                          │                 │  IN4: ESP GPIO14│               │
      ┌───────┬───────┬───┴───┐             │  ENA: ESP GPIO32│               │
      │       │       │       │             │  ENB: ESP GPIO33│               │
      │       │       │       │             │                 │               │
 ┌────┴──┐ ┌──┴───┐ ┌─┴────┐ │             │  OUT1: L motor+ │               │
 │ Pi 3B │ │ESP32 │ │HC-SR04│ │             │  OUT2: L motor- │               │
 │ micro │ │ VIN  │ │VCC x2│ │             │  OUT3: R motor+ │               │
 │ USB   │ │(5V)  │ │(5V)  │ │             │  OUT4: R motor- │               │
 │ power │ │      │ │      │ │             └─────────────────┘               │
 └───────┘ └──────┘ └──────┘ │                  │  │  │  │                   │
                              │                  │  │  │  │                   │
                         ┌────┴──────┐      ┌────┘  │  │  └────┐             │
                         │ Level     │      │       │  │       │             │
                         │ Shifter   │   ┌──┴──┐ ┌──┴──┴──┐ ┌──┴──┐         │
                         │ HV: 5V   │   │ LEFT │ │        │ │RIGHT│         │
                         │ LV: 3.3V │   │ TT   │ │        │ │ TT  │         │
                         └──────────┘   │MOTOR │ │        │ │MOTOR│         │
                                        └──┬───┘ │        │ └──┬──┘         │
                                           │     │        │    │            │
                                        ENCODER  │        │ ENCODER        │
                                        signals  │        │ signals        │
                                        to ESP32 │        │ to ESP32       │
                                        GPIO34/35│        │ GPIO36/39      │
                                                 │        │                │
                                                 └────────┘                │

═══════════════════════════════════════════════════════════════════════════════
                           SIGNAL CONNECTIONS
═══════════════════════════════════════════════════════════════════════════════

    Pi 3B                           ESP32
   ┌──────────────────┐           ┌──────────────────┐
   │                  │           │                  │
   │  GPIO14 (TX)  ───│── white ──│──→ GPIO16 (RX)  │  UART (115200, 3.3V)
   │  Pin 8           │           │                  │
   │                  │           │                  │
   │  GPIO15 (RX)  ←──│── green ──│─── GPIO17 (TX)  │
   │  Pin 10          │           │                  │
   │                  │           │                  │
   │  GND (Pin 6)  ───│── black ──│─── GND          │  Common ground
   │                  │           │                  │
   │                  │           │  GPIO25 ─────────│──→ L293D IN1
   │                  │           │  GPIO26 ─────────│──→ L293D IN2
   │                  │           │  GPIO27 ─────────│──→ L293D IN3
   │                  │           │  GPIO14 ─────────│──→ L293D IN4
   │                  │           │  GPIO32 (PWM) ───│──→ L293D ENA
   │                  │           │  GPIO33 (PWM) ───│──→ L293D ENB
   │                  │           │                  │
   │                  │           │  GPIO34 ←────────│─── L Encoder A
   │                  │           │  GPIO35 ←────────│─── L Encoder B
   │                  │           │  GPIO36 ←────────│─── R Encoder A
   │                  │           │  GPIO39 ←────────│─── R Encoder B
   │                  │           │                  │
   │  GPIO2 (SDA) ────│── blue ──→│  (not connected) │
   │  Pin 3       ────│── to ────→│  I2C is on Pi    │
   │                  │  MPU6050  │                  │
   │  GPIO3 (SCL) ────│── purple─→│                  │
   │  Pin 5           │  to      │                  │
   │                  │  MPU6050  │                  │
   │                  │           │                  │
   │  USB ────────────│── webcam  │                  │
   │                  │           │                  │
   │  GPIO22 (out) ───│── pink ──────────────────────│──→ HC-SR04 L TRIG
   │  Pin 15          │           │                  │
   │  GPIO23 (out) ───│── pink ──────────────────────│──→ HC-SR04 R TRIG
   │  Pin 16          │           │                  │
   │                  │           │                  │
   │  GPIO17 (in) ←───│── tan ── LV1 ←── HV1 ──────│─── HC-SR04 L ECHO
   │  Pin 11          │     (level shifter)          │
   │  GPIO27 (in) ←───│── tan ── LV2 ←── HV2 ──────│─── HC-SR04 R ECHO
   │  Pin 13          │     (level shifter)          │
   │                  │           │                  │
   └──────────────────┘           └──────────────────┘

    MPU6050                Level Shifter (4-ch)
   ┌──────────┐           ┌──────────────────┐
   │ VCC ← 3.3V (Pi)     │ LV ← 3.3V (Pi)  │
   │ GND ← GND           │ HV ← 5V rail     │
   │ SDA → Pi GPIO2      │ GND ← GND        │
   │ SCL → Pi GPIO3      │                  │
   │ AD0 → GND           │ LV1 → Pi GPIO17  │
   │ INT → NC             │ HV1 ← SR04 L ECHO│
   └──────────┘           │ LV2 → Pi GPIO27  │
                          │ HV2 ← SR04 R ECHO│
                          │ LV3 → NC (spare) │
                          │ HV3 → NC (spare) │
                          │ LV4 → NC (spare) │
                          │ HV4 → NC (spare) │
                          └──────────────────┘
```

### 16.2 Ground Bus Detail

ALL ground connections must be tied together. Use a breadboard ground rail or a terminal block as the central ground bus.

```
    GND BUS (terminal block or breadboard rail)
    ─────────────────────────────────────────────
      │    │    │    │    │     │     │     │    │
     Batt  Pi  ESP32 Buck L293D SR04L SR04R MPU  LvlShift
     (-)  GND  GND   GND  GND  GND   GND   GND  GND
```

**If you get weird behavior** (sensors reading wrong, motors twitching, serial corruption), the FIRST thing to check is whether all grounds are solidly connected to the same bus. A floating ground is the most common wiring bug.

---

## 17. Safety Notes and Current Budget

### 17.1 Voltage and Level Shifting

| Risk | Mitigation |
|---|---|
| 7.4V to Pi (destroys Pi instantly) | Verify buck converter output with multimeter BEFORE connecting Pi. NEVER connect battery direct to Pi. |
| 5V to Pi GPIO (damages GPIO pin) | Level shift ALL 5V signals. HC-SR04 echo pins go through level shifter. |
| 5V to ESP32 GPIO (may damage ESP32) | ESP32 GPIOs are 3.3V. Do not connect 5V signals to ESP32 GPIO pins. Encoder outputs should be 3.3V (powered from 3.3V rail). |
| Backfeed from motor driver | Remove power jumper on L293D shield. Keep motor voltage and logic voltage on separate paths. |

### 17.2 Current Budget

| Device | Max Current Draw | Supply Rail |
|---|---|---|
| Raspberry Pi 3B | 1.4A typical, 2.5A peak (with USB devices) | 5V (via micro-USB) |
| ESP32 DevKit | 0.5A peak (with WiFi active) | 5V (via VIN) |
| HC-SR04 x2 | 15mA each, 30mA total | 5V |
| MPU6050 | 3.9mA | 3.3V |
| Level shifter | < 1mA | 3.3V + 5V |
| USB webcam | 200-500mA | 5V (via Pi USB) |
| **Total 5V rail** | **~3.5-4.5A peak** | **Buck converter must supply this** |

| Device | Max Current Draw | Supply Rail |
|---|---|---|
| TT motor x2 (no load) | 200mA each, 400mA total | 7.4V (through L293D) |
| TT motor x2 (stall) | 800mA-1.2A each, up to 2.4A total | 7.4V (through L293D) |
| L293D driver losses | ~30% overhead at rated current | 7.4V |
| **Total motor rail** | **~0.5-3A** | **Battery direct** |

### 17.3 Fuse Recommendations

| Location | Fuse Rating | Type | Purpose |
|---|---|---|---|
| Battery positive lead (after kill switch) | **5A** blade fuse | Automotive mini blade | Protects entire system from short circuit |
| 5V rail (buck converter output) | **4A** polyfuse (resettable) | PTC thermistor | Protects Pi + ESP32 from overcurrent |
| Motor supply (battery to L293D VS) | **3A** blade fuse | Automotive mini blade | Protects L293D and wiring from motor stall overcurrent |

**For v1, fuses are recommended but not mandatory.** The kill switch is the primary safety device. Add fuses when transitioning from bench testing to mobile operation.

### 17.4 L293D Current Limits

The L293D is rated at **600mA per channel** continuous, **1.2A peak**. TT motors can draw up to 800mA-1.2A at stall. This means:

- **Normal operation:** Fine. TT motors draw ~200-400mA under load.
- **Stall condition:** The L293D may overheat or shut down. This is actually a SAFETY FEATURE -- it limits stall current and protects the motor.
- **If L293D overheats regularly:** Upgrade to an L298N (2A per channel) or TB6612FNG (1.2A per channel, more efficient).

The L293D is adequate for v1 bench testing and light-load floor driving. It is the weakest link in the power chain and will be the first thing upgraded if needed.

### 17.5 Wire Gauge Recommendations

| Wire Run | Minimum Gauge | Notes |
|---|---|---|
| Battery to kill switch | 18 AWG | Carries full system current |
| Kill switch to bus | 18 AWG | Carries full system current |
| Bus to buck converter | 20 AWG | Up to 4-5A at 7.4V |
| Bus to L293D motor supply | 20 AWG | Up to 3A |
| Buck converter to Pi (micro-USB) | 22 AWG | 2-3A at 5V |
| Buck converter to ESP32 VIN | 22 AWG | < 1A |
| Signal wires (UART, I2C, GPIO) | 26-28 AWG (jumper wire) | Milliamp-level signals |
| Motor wires (L293D to motors) | 22 AWG | Up to 1A per motor |

### 17.6 ESD and Handling

- **Always disconnect the battery** before wiring or rewiring anything.
- **Touch a grounded metal object** before handling the Pi or ESP32 (static discharge can kill them).
- **Never hot-plug the IMU or level shifter** while the system is powered -- I2C bus can latch up.
- **Never plug or unplug motor wires while PWM is active** -- inductive kickback can damage the driver.

---

## 18. Pre-Power Checklist

Run through this checklist EVERY TIME before applying power. This is **Constitution Article 13.1** (Pre-Action Verification) applied to the wiring bench.

### 18.1 Before First Power-Up

- [ ] Kill switch is in OFF position
- [ ] Buck converter output verified at 5.00-5.10V with multimeter (use bench supply to test converter, NOT the battery)
- [ ] No bare wire ends touching each other or the chassis
- [ ] All grounds connected to the same bus (continuity test with multimeter)
- [ ] Pi micro-USB power cable connected to 5V rail (NOT 7.4V rail)
- [ ] ESP32 VIN connected to 5V rail (NOT 7.4V rail)
- [ ] L293D motor supply (VS) connected to 7.4V rail
- [ ] L293D logic supply (VSS) connected to 5V rail
- [ ] L293D power jumper REMOVED (motor voltage isolated from logic)
- [ ] Level shifter LV connected to 3.3V, HV connected to 5V
- [ ] HC-SR04 ECHO pins go through level shifter (NOT direct to Pi)
- [ ] Pi UART TX (pin 8) connects to ESP32 RX (GPIO16) -- NOT TX to TX
- [ ] Pi UART RX (pin 10) connects to ESP32 TX (GPIO17) -- NOT RX to RX
- [ ] Encoder pull-up resistors (10k to 3.3V) installed on GPIO34, 35, 36, 39
- [ ] MPU6050 powered from 3.3V (NOT 5V)
- [ ] No wires pinched under boards or standoffs

### 18.2 Power-Up Sequence

1. Kill switch OFF
2. Connect battery to kill switch input
3. Verify no smoke, no heat, no LEDs lighting up (everything should be dead)
4. Flip kill switch ON
5. Check: Buck converter LED (if present) should light
6. Check: Pi red LED should light, then green LED should blink (booting)
7. Check: ESP32 LED should light (powered)
8. Wait for Pi to fully boot (30-60 seconds)
9. SSH into Pi: `ssh evobot`
10. Run `i2cdetect -y 1` -- verify MPU6050 at 0x68
11. Test serial: `echo "H" > /dev/ttyAMA0` -- ESP32 should respond
12. Test motors at LOW speed first: `M 50 50` -- both wheels should turn slowly forward
13. Test kill switch: flip OFF while motors are running -- everything should stop instantly

### 18.3 After Any Wiring Change

- [ ] Kill switch OFF before touching any wire
- [ ] Re-run the full pre-power checklist (Section 18.1)
- [ ] Power up and re-verify all subsystems

---

## Appendix A: Quick Reference — Connection Summary

| From | To | Wire | Signal | Voltage |
|---|---|---|---|---|
| Battery (+) | Kill switch IN | Red | Power | 7.4V |
| Kill switch OUT | Buck IN+ / L293D VS | Orange | Power | 7.4V |
| Battery (-) | GND bus | Black | Ground | 0V |
| Buck OUT+ | Pi USB / ESP32 VIN / sensors | Yellow | Power | 5.0V |
| Buck OUT- | GND bus | Black | Ground | 0V |
| Pi pin 1 | MPU6050 VCC / LvlShift LV | Red (3V3) | Power | 3.3V |
| Pi pin 8 (GPIO14 TX) | ESP32 GPIO16 (RX) | White | UART TX | 3.3V |
| Pi pin 10 (GPIO15 RX) | ESP32 GPIO17 (TX) | Green | UART RX | 3.3V |
| Pi pin 3 (GPIO2) | MPU6050 SDA | Blue | I2C SDA | 3.3V |
| Pi pin 5 (GPIO3) | MPU6050 SCL | Purple | I2C SCL | 3.3V |
| Pi pin 15 (GPIO22) | HC-SR04 LEFT Trig | Pink | GPIO out | 3.3V |
| Pi pin 16 (GPIO23) | HC-SR04 RIGHT Trig | Pink | GPIO out | 3.3V |
| Pi pin 11 (GPIO17) | LvlShift LV1 | Tan | Echo (shifted) | 3.3V |
| Pi pin 13 (GPIO27) | LvlShift LV2 | Tan | Echo (shifted) | 3.3V |
| LvlShift HV1 | HC-SR04 LEFT Echo | Tan | Echo (raw) | 5.0V |
| LvlShift HV2 | HC-SR04 RIGHT Echo | Tan | Echo (raw) | 5.0V |
| ESP32 GPIO25 | L293D IN1 | -- | Motor A dir | 3.3V |
| ESP32 GPIO26 | L293D IN2 | -- | Motor A dir | 3.3V |
| ESP32 GPIO27 | L293D IN3 | -- | Motor B dir | 3.3V |
| ESP32 GPIO14 | L293D IN4 | -- | Motor B dir | 3.3V |
| ESP32 GPIO32 | L293D ENA | -- | Motor A PWM | 3.3V |
| ESP32 GPIO33 | L293D ENB | -- | Motor B PWM | 3.3V |
| ESP32 GPIO34 | Left encoder ch A | Grey | Encoder | 3.3V |
| ESP32 GPIO35 | Left encoder ch B | Grey | Encoder | 3.3V |
| ESP32 GPIO36 | Right encoder ch A | Grey | Encoder | 3.3V |
| ESP32 GPIO39 | Right encoder ch B | Grey | Encoder | 3.3V |
| L293D OUT1/OUT2 | Left TT motor | Brown | Motor power | 0-7.4V |
| L293D OUT3/OUT4 | Right TT motor | Brown | Motor power | 0-7.4V |
| Pi USB port | USB webcam | USB cable | Video | 5V USB |

---

## Appendix B: Required Passive Components

| Component | Quantity | Purpose | Location |
|---|---|---|---|
| 10k ohm resistor (1/4W) | 4 | Encoder pull-ups (GPIO34, 35, 36, 39) | Mini breadboard near ESP32 |
| 4.7k ohm resistor (1/4W) | 2 | I2C pull-ups (if not on MPU6050 board) | Near MPU6050 or Pi header |
| 5A blade fuse + holder | 1 | Main power protection | Inline after kill switch |
| 3A blade fuse + holder | 1 | Motor supply protection | Inline before L293D VS |

---

## Appendix C: Test Points

When debugging, check these voltages with a multimeter. Kill switch must be ON.

| Test Point | Expected Voltage | Measured | OK? |
|---|---|---|---|
| Battery pack terminals | 7.0-8.4V | _______ | [ ] |
| After kill switch (orange bus) | Same as battery | _______ | [ ] |
| Buck converter output (5V rail) | 4.95-5.10V | _______ | [ ] |
| Pi 3.3V pin (pin 1) | 3.25-3.35V | _______ | [ ] |
| ESP32 3.3V pin | 3.25-3.35V | _______ | [ ] |
| L293D VSS (logic supply) | 4.95-5.10V | _______ | [ ] |
| L293D VS (motor supply) | Same as battery | _______ | [ ] |
| HC-SR04 VCC | 4.95-5.10V | _______ | [ ] |
| MPU6050 VCC | 3.25-3.35V | _______ | [ ] |
| Level shifter LV | 3.25-3.35V | _______ | [ ] |
| Level shifter HV | 4.95-5.10V | _______ | [ ] |

---

*This wiring document is the single source of truth for reference-01 electrical connections. If the physical wiring disagrees with this document, one of them is wrong. Fix it before powering on.*

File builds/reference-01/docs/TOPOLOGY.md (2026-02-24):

# EvoBot System Topology

## Overview

Three distinct layers with clear separation of responsibilities.

```
┌──────────────────────────────────────────────────────────────────┐
│  LAYER 1: DEVELOPMENT (Windows 10 Workstation / WSL)            │
│                                                                  │
│  Scott (human) ←→ Claude Code (WSL/bash)                        │
│                      │                                           │
│                      ├── SSH to Pi (deploy, debug, configure)    │
│                      ├── Git ←→ GitHub (version control)         │
│                      └── Internet (Anthropic API for Claude Code)│
│                                                                  │
│  Role: Architecture, code writing, design, review, iteration     │
│  Claude Code is the DEVELOPMENT TOOL — not the robot's brain    │
├──────────────────────────────────────────────────────────────────┤
│  LAYER 2: ROBOT BRAIN (Pi 3B @ 192.168.1.51)                    │
│                                                                  │
│  Robot Python Code (main loop)                                   │
│      │                                                           │
│      ├── Ollama (LAN server) ── routine inference, local-first  │
│      ├── Claude API (HTTP) ──── complex reasoning, self-evolution│
│      ├── ESP32 (UART serial) ── motor commands, encoder reads   │
│      ├── Sensors (I2C/GPIO) ── IMU, ultrasonic, camera          │
│      └── Logging / self-evaluation                               │
│                                                                  │
│  Role: Autonomous operation, decision-making, perception, action │
│  Pi stays LEAN — no Node.js, no Claude Code CLI, no IDE         │
├──────────────────────────────────────────────────────────────────┤
│  LAYER 3: REAL-TIME (ESP32 / Pico / Arduino)                     │
│                                                                  │
│  Motor PWM generation                                            │
│  Encoder pulse counting                                          │
│  PID loop (constant-rate, microsecond precision)                 │
│  Safety watchdog (independent of Pi)                             │
│                                                                  │
│  Role: Physics-layer control that Linux can't reliably do       │
└──────────────────────────────────────────────────────────────────┘
```

## Connection Map

```
[Workstation WSL] ──SSH──→ [Pi 3B eth0 192.168.1.51]
                                │
                    ┌───────────┼───────────────┐
                    │           │               │
              [UART/Serial] [I2C Bus]     [USB Port]
                    │           │               │
               [ESP32]    [IMU, ADC,       [Webcam]
              Motor Ctrl   RTC, etc.]
              + Encoders
              + Safety
                    │
              [Motor Driver]
                    │
              [TT Motors]
```

## Network

| Device | IP | Access | Purpose |
|---|---|---|---|
| Workstation (WSL) | 192.168.1.x (DHCP) | — | Development hub |
| EvoBot Pi 3B | 192.168.1.51 (static) | `ssh evobot` | Robot brain |
| Sensor Pi (DO NOT TOUCH) | 192.168.1.48 (static) | — | Heat pump monitoring |
| Home Assistant | 192.168.1.151 | — | Home automation (future integration) |
| Ollama server | TBD | HTTP API | Local LLM inference |
| Internet | — | Pi WiFi | Claude API, updates |

## Why Not Claude Code on the Pi?

Tested and verified: Claude Code runs on Pi 3 (64-bit OS) but is very slow and resource-hungry.

| Factor | Impact |
|---|---|
| Node.js on ARM | 200-400MB RAM of 921MB total |
| Response latency | Painful on 1.2GHz Cortex-A53 |
| Resource competition | Starves robot code of CPU/RAM |
| Unnecessary overhead | Robot needs HTTP API calls, not a full CLI with file editing + git |
| Internet dependency | Claude Code always needs internet; robot should survive disconnection |

**The robot calls the Claude API directly via Python `requests` (~20 lines of code).** Same inference capability, 1% of the overhead.

## Inference Routing (Local-First)

```python
# Pseudocode for robot's inference decision
def get_inference(prompt, complexity="routine"):
    if complexity == "routine":
        return call_ollama(prompt)        # LAN, no internet needed
    elif complexity == "complex":
        try:
            return call_claude_api(prompt) # Cloud, for self-evolution reasoning
        except ConnectionError:
            return call_ollama(prompt)     # Fallback to local if offline
```

The robot's thinking degrades gracefully — if internet drops, it falls back to Ollama. If Ollama is down, it falls back to cached heuristics. Core motor control and safety never depend on any inference service.

## Deployment Flow

```
1. Claude Code (WSL) writes/edits code in Documents/EvoBot/code/
2. Git commit + push to GitHub
3. SCP deploy to Pi:
   scp -r code/ evobot:~/evobot/src/
4. SSH to Pi, restart services:
   ssh evobot 'systemctl --user restart evobot'
```

Future: automated deploy via git hooks or CI.

---

*This topology is designed for the Pi 3 resource constraints. If the brain upgrades to Pi 4/5 or Orange Pi 5, the layers remain the same but capabilities expand.*

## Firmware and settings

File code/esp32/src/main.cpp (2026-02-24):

// =============================================================================
// EvoBot reference-01 — ESP32 Motor Control Firmware
// =============================================================================
// This firmware runs on the ESP32 and is responsible for:
//   1. Receiving motor commands from the Raspberry Pi over UART2
//   2. Running PID loops to maintain commanded velocities using encoder feedback
//   3. Independently monitoring for safety conditions (watchdog)
//   4. Reporting encoder data and status back to the Pi
//
// The ESP32 does NOT make decisions. It does not think. It executes motor
// commands faithfully and stops the motors if the Pi goes silent.
// This is the hard safety layer — Constitution Article 14.
//
// Boot sequence:
//   1. Initialize hardware (pins, PWM, UART, encoders)
//   2. Motors are OFF (BOOT state, waiting for first heartbeat)
//   3. Wait for Pi to send 'H' (heartbeat) to transition to ACTIVE
//   4. Once ACTIVE, process motor commands and run PID loops
//   5. If heartbeats stop → TIMED_OUT → motors killed
//   6. If 'E' received → E_STOP → motors locked until 'R' (reset)
//
// Safety invariant: every code path that can reach motor output passes
// through the watchdog check first. If motorsAllowed() is false, the
// motors stay at zero regardless of what commands arrive.
// =============================================================================

#include <Arduino.h>
#include "config.h"
#include "pid.h"
#include "motors.h"
#include "encoders.h"
#include "watchdog.h"
#include "serial_protocol.h"

// ---------------------------------------------------------------------------
// Global objects
// ---------------------------------------------------------------------------
Motors motors;
Encoders encoders;
Watchdog watchdog;
SerialProtocol protocol;
PIDController pidLeft;
PIDController pidRight;

// ---------------------------------------------------------------------------
// PID state
// ---------------------------------------------------------------------------
// Target speeds as received from the Pi (-100 to +100).
// These are converted to target ticks-per-interval for the PID.
int targetLeftSpeed = 0;
int targetRightSpeed = 0;

// PID loop timing
unsigned long lastPIDTime = 0;

// Encoder speed tracking (ticks per second, smoothed)
float leftTicksPerSec = 0.0f;
float rightTicksPerSec = 0.0f;

// Smoothing factor for speed calculation (exponential moving average)
// Lower = smoother but more lag. 0.3 is a reasonable starting point.
const float SPEED_SMOOTH_ALPHA = 0.3f;

// ---------------------------------------------------------------------------
// Debug helper
// ---------------------------------------------------------------------------
#if DEBUG_ENABLED
    #define DEBUG_PRINT(x)   Serial.print(x)
    #define DEBUG_PRINTLN(x) Serial.println(x)
#else
    #define DEBUG_PRINT(x)
    #define DEBUG_PRINTLN(x)
#endif

// ===========================================================================
// setup() — called once at boot
// ===========================================================================
void setup() {
    // --- Debug serial (USB console) ---
    #if DEBUG_ENABLED
    Serial.begin(115200);
    delay(100);
    Serial.println();
    Serial.println("==========================================");
    Serial.println("EvoBot reference-01 — ESP32 Motor Firmware");
    Serial.println("==========================================");
    Serial.println("State: BOOT (motors disabled, waiting for heartbeat)");
    #endif

    // --- Initialize subsystems ---

    // Serial protocol (UART2 to Pi)
    protocol.init();
    DEBUG_PRINTLN("[INIT] UART2 initialized (Pi link)");

    // Encoder ISRs
    encoders.init();
    DEBUG_PRINTLN("[INIT] Encoders initialized (ISR attached)");

    // Motor driver (PWM channels, direction pins)
    motors.init();
    DEBUG_PRINTLN("[INIT] Motors initialized (PWM off, direction pins LOW)");

    // PID controllers
    pidLeft.init(PID_KP_DEFAULT, PID_KI_DEFAULT, PID_KD_DEFAULT);
    pidRight.init(PID_KP_DEFAULT, PID_KI_DEFAULT, PID_KD_DEFAULT);
    DEBUG_PRINTLN("[INIT] PID controllers initialized");
    DEBUG_PRINT("[INIT] PID gains: Kp=");
    DEBUG_PRINT(PID_KP_DEFAULT);
    DEBUG_PRINT(" Ki=");
    DEBUG_PRINT(PID_KI_DEFAULT);
    DEBUG_PRINT(" Kd=");
    DEBUG_PRINTLN(PID_KD_DEFAULT);

    // Safety watchdog
    watchdog.init(WATCHDOG_TIMEOUT_MS);
    DEBUG_PRINT("[INIT] Watchdog initialized, timeout=");
    DEBUG_PRINT(WATCHDOG_TIMEOUT_MS);
    DEBUG_PRINTLN("ms");

    // PID loop timer
    lastPIDTime = millis();

    DEBUG_PRINTLN("[INIT] Boot complete. Waiting for first heartbeat...");
    DEBUG_PRINTLN();
}

// ===========================================================================
// loop() — runs continuously
// ===========================================================================
void loop() {
    unsigned long now = millis();

    // -----------------------------------------------------------------------
    // 1. WATCHDOG CHECK — runs every iteration, before anything else.
    //    This is the hard safety net. If the Pi is unresponsive, we kill
    //    the motors before processing any other logic.
    // -----------------------------------------------------------------------
    bool watchdogJustFired = watchdog.check();

    if (watchdogJustFired) {
        // Watchdog just transitioned to TIMED_OUT.
        // Kill motors immediately and notify Pi (if it's listening).
        motors.eStop();
        targetLeftSpeed = 0;
        targetRightSpeed = 0;
        pidLeft.reset();
        pidRight.reset();

        protocol.sendWatchdogTimeout();

        DEBUG_PRINTLN("[WDT] Watchdog timeout! Motors killed.");
    }

    // -----------------------------------------------------------------------
    // 2. SERIAL COMMAND PROCESSING — non-blocking read and dispatch.
    // -----------------------------------------------------------------------
    if (protocol.available()) {
        Command cmd = protocol.readCommand();

        switch (cmd.type) {

            // --- H: Heartbeat ---
            // Resets the watchdog timer. This is the lifeblood of the
            // safety system. If the Pi is alive, it sends this regularly.
            case CMD_HEARTBEAT:
                watchdog.feed();
                protocol.sendOK();
                DEBUG_PRINTLN("[CMD] Heartbeat received");
                break;

            // --- M <left> <right>: Motor speed command ---
            // Sets target velocity for PID control. Only processed if
            // the watchdog allows motor operation.
            case CMD_MOTOR:
                if (watchdog.getState() == WDT_E_STOP) {
                    protocol.sendError("ESTOP_LOCKED",
                        "E-stop active, send R to reset");
                    DEBUG_PRINTLN("[CMD] Motor command rejected: E_STOP active");
                } else if (!watchdog.motorsAllowed()) {
                    protocol.sendError("NOT_ACTIVE",
                        "No heartbeat received yet or watchdog timed out");
                    DEBUG_PRINTLN("[CMD] Motor command rejected: not ACTIVE");
                } else {
                    targetLeftSpeed = cmd.leftSpeed;
                    targetRightSpeed = cmd.rightSpeed;
                    protocol.sendOK();
                    DEBUG_PRINT("[CMD] Motor: L=");
                    DEBUG_PRINT(cmd.leftSpeed);
                    DEBUG_PRINT(" R=");
                    DEBUG_PRINTLN(cmd.rightSpeed);
                }
                break;

            // --- S: Controlled stop ---
            // Ramp motors to zero gracefully.
            case CMD_STOP:
                targetLeftSpeed = 0;
                targetRightSpeed = 0;
                motors.stop();
                pidLeft.reset();
                pidRight.reset();
                protocol.sendOK();
                DEBUG_PRINTLN("[CMD] Controlled stop");
                break;

            // --- E: Emergency stop ---
            // Immediate zero, lockout until reset. Constitution Art. 14.
            case CMD_E_STOP:
                motors.eStop();
                targetLeftSpeed = 0;
                targetRightSpeed = 0;
                pidLeft.reset();
                pidRight.reset();
                watchdog.triggerEStop();
                protocol.sendOK();
                DEBUG_PRINTLN("[CMD] EMERGENCY STOP — motors locked");
                break;

            // --- R: Reset after e-stop ---
            // Clears the e-stop lockout. Motors remain off until the Pi
            // sends a new heartbeat (transitions through BOOT → ACTIVE).
            case CMD_RESET:
                watchdog.reset();
                motors.eStop();  // Ensure motors are off during transition
                targetLeftSpeed = 0;
                targetRightSpeed = 0;
                pidLeft.reset();
                pidRight.reset();
                protocol.sendOK();
                DEBUG_PRINTLN("[CMD] Reset — waiting for heartbeat");
                break;

            // --- E?: Request encoder data ---
            case CMD_GET_ENCODERS: {
                long lt = encoders.getLeftTicks();
                long rt = encoders.getRightTicks();
                protocol.sendEncoderData(lt, rt, leftTicksPerSec, rightTicksPerSec);
                DEBUG_PRINT("[CMD] Encoders: L=");
                DEBUG_PRINT(lt);
                DEBUG_PRINT(" R=");
                DEBUG_PRINTLN(rt);
                break;
            }

            // --- S?: Request status ---
            case CMD_GET_STATUS:
                protocol.sendStatus(
                    watchdog.getStateName(),
                    watchdog.getUptime(),
                    watchdog.getTimeRemaining()
                );
                DEBUG_PRINT("[CMD] Status: ");
                DEBUG_PRINTLN(watchdog.getStateName());
                break;

            // --- P <Kp> <Ki> <Kd>: Set PID parameters ---
            case CMD_SET_PID:
                pidLeft.setGains(cmd.kp, cmd.ki, cmd.kd);
                pidRight.setGains(cmd.kp, cmd.ki, cmd.kd);
                protocol.sendOK();
                DEBUG_PRINT("[CMD] PID: Kp=");
                DEBUG_PRINT(cmd.kp);
                DEBUG_PRINT(" Ki=");
                DEBUG_PRINT(cmd.ki);
                DEBUG_PRINT(" Kd=");
                DEBUG_PRINTLN(cmd.kd);
                break;

            // --- Unknown or malformed command ---
            case CMD_UNKNOWN:
                protocol.sendError("BAD_CMD", cmd.errorMsg.c_str());
                DEBUG_PRINT("[CMD] Unknown: ");
                DEBUG_PRINTLN(cmd.errorMsg);
                break;

            // --- Empty line or parse failure ---
            case CMD_NONE:
            default:
                break;
        }
    }

    // -----------------------------------------------------------------------
    // 3. PID LOOP — runs at PID_LOOP_HZ (50 Hz, every 20ms).
    //    Only drives motors when watchdog allows it.
    // -----------------------------------------------------------------------
    if (now - lastPIDTime >= PID_LOOP_INTERVAL_MS) {
        float dt = (float)(now - lastPIDTime) / 1000.0f;  // seconds
        lastPIDTime = now;

        // Read encoder deltas (ticks since last PID cycle)
        long leftDelta = encoders.getLeftDelta();
        long rightDelta = encoders.getRightDelta();

        // Calculate ticks per second with exponential smoothing
        float rawLeftTPS = (float)leftDelta / dt;
        float rawRightTPS = (float)rightDelta / dt;

        leftTicksPerSec = (SPEED_SMOOTH_ALPHA * rawLeftTPS) +
                          ((1.0f - SPEED_SMOOTH_ALPHA) * leftTicksPerSec);
        rightTicksPerSec = (SPEED_SMOOTH_ALPHA * rawRightTPS) +
                           ((1.0f - SPEED_SMOOTH_ALPHA) * rightTicksPerSec);

        // Only run PID and drive motors if watchdog allows it
        if (watchdog.motorsAllowed()) {

            if (targetLeftSpeed == 0 && targetRightSpeed == 0) {
                // Both targets are zero — set motors off directly, skip PID.
                // This prevents PID integral from winding up while stopped.
                motors.setLeftPWM(0, 0);
                motors.setRightPWM(0, 0);
                pidLeft.reset();
                pidRight.reset();
            } else {
                // --- Left motor PID ---
                float leftSetpoint = (float)targetLeftSpeed * SPEED_TO_TICKS_SCALE;
                float leftMeasurement = (float)leftDelta;  // ticks this interval

                // The PID computes based on absolute values. Direction is
                // determined by the sign of the target speed.
                float leftAbsSetpoint = fabsf(leftSetpoint);
                float leftAbsMeasurement = fabsf(leftMeasurement);

                float leftPWM = pidLeft.compute(leftAbsSetpoint, leftAbsMeasurement, dt);

                int leftDir = 0;
                if (targetLeftSpeed > 0) leftDir = 1;
                else if (targetLeftSpeed < 0) leftDir = -1;

                // Apply deadband: if target is within deadband, set PWM to 0
                if (abs(targetLeftSpeed) < SPEED_DEADBAND) {
                    leftPWM = 0;
                    leftDir = 0;
                }

                motors.setLeftPWM((int)leftPWM, leftDir);

                // --- Right motor PID ---
                float rightSetpoint = (float)targetRightSpeed * SPEED_TO_TICKS_SCALE;
                float rightMeasurement = (float)rightDelta;

                float rightAbsSetpoint = fabsf(rightSetpoint);
                float rightAbsMeasurement = fabsf(rightMeasurement);

                float rightPWM = pidRight.compute(rightAbsSetpoint, rightAbsMeasurement, dt);

                int rightDir = 0;
                if (targetRightSpeed > 0) rightDir = 1;
                else if (targetRightSpeed < 0) rightDir = -1;

                if (abs(targetRightSpeed) < SPEED_DEADBAND) {
                    rightPWM = 0;
                    rightDir = 0;
                }

                motors.setRightPWM((int)rightPWM, rightDir);
            }
        } else {
            // Motors not allowed (BOOT, TIMED_OUT, or E_STOP).
            // Ensure motors are at zero and PID is reset.
            motors.setLeftPWM(0, 0);
            motors.setRightPWM(0, 0);
            pidLeft.reset();
            pidRight.reset();
        }
    }

    // -----------------------------------------------------------------------
    // 4. Small yield to prevent watchdog task starvation on ESP32.
    //    The ESP32 has a built-in task watchdog that fires if loop() never
    //    yields. A 1ms delay is sufficient and doesn't affect timing.
    // -----------------------------------------------------------------------
    delay(1);
}

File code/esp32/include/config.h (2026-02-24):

// =============================================================================
// EvoBot reference-01 — ESP32 Motor Controller Configuration
// =============================================================================
// All pin definitions and tunable constants live here. Change this file
// to adapt the firmware to different wiring or hardware. No magic numbers
// should exist anywhere else in the codebase.
//
// Pin assignments match WIRING.md (the single source of truth for electrical
// connections). If this file disagrees with WIRING.md, fix this file.
// =============================================================================

#ifndef CONFIG_H
#define CONFIG_H

// ---------------------------------------------------------------------------
// Motor A (Left) — L293D channel A
// ---------------------------------------------------------------------------
#define MOTOR_A_IN1     25      // GPIO25 → L293D IN1 (direction pin 1)
#define MOTOR_A_IN2     26      // GPIO26 → L293D IN2 (direction pin 2)
#define MOTOR_A_ENA     32      // GPIO32 → L293D ENA (PWM speed control)

// ---------------------------------------------------------------------------
// Motor B (Right) — L293D channel B
// ---------------------------------------------------------------------------
#define MOTOR_B_IN3     27      // GPIO27 → L293D IN3 (direction pin 1)
#define MOTOR_B_IN4     14      // GPIO14 → L293D IN4 (direction pin 2)
#define MOTOR_B_ENB     33      // GPIO33 → L293D ENB (PWM speed control)

// ---------------------------------------------------------------------------
// PWM Configuration
// ---------------------------------------------------------------------------
#define PWM_FREQ        20000   // 20 kHz — above human hearing, no motor whine
#define PWM_RESOLUTION  8       // 8-bit resolution: 0-255 duty cycle
#define PWM_CHANNEL_A   0       // LEDC channel for Motor A
#define PWM_CHANNEL_B   1       // LEDC channel for Motor B

// ---------------------------------------------------------------------------
// Encoder Inputs (ESP32 input-only GPIOs — external 10k pull-ups required)
// ---------------------------------------------------------------------------
#define ENC_LEFT_A      34      // GPIO34 — Left motor encoder channel A
#define ENC_LEFT_B      35      // GPIO35 — Left motor encoder channel B
#define ENC_RIGHT_A     36      // GPIO36 (VP) — Right motor encoder channel A
#define ENC_RIGHT_B     39      // GPIO39 (VN) — Right motor encoder channel B

// ---------------------------------------------------------------------------
// UART2 — Serial link to Raspberry Pi
// ---------------------------------------------------------------------------
#define UART_RX_PIN     16      // GPIO16 — receives commands from Pi TX (GPIO14)
#define UART_TX_PIN     17      // GPIO17 — sends data to Pi RX (GPIO15)
#define UART_BAUD       115200  // 115200 baud, 8N1, no flow control

// ---------------------------------------------------------------------------
// PID Controller Defaults
// ---------------------------------------------------------------------------
// These are starting values. Tune empirically on real hardware.
// Adjustable at runtime via the 'P <Kp> <Ki> <Kd>' serial command.
#define PID_KP_DEFAULT  2.0f
#define PID_KI_DEFAULT  0.5f
#define PID_KD_DEFAULT  0.1f

// Output limits — PID output is clamped to valid PWM range
#define PID_OUTPUT_MIN  0.0f
#define PID_OUTPUT_MAX  255.0f

// Anti-windup: maximum absolute value the integral term can accumulate.
// Prevents integral windup when the motor is saturated or stalled.
#define PID_INTEGRAL_MAX 200.0f

// ---------------------------------------------------------------------------
// PID Loop Timing
// ---------------------------------------------------------------------------
#define PID_LOOP_HZ     50      // PID runs at 50 Hz (every 20ms)
#define PID_LOOP_INTERVAL_MS (1000 / PID_LOOP_HZ)  // 20ms

// ---------------------------------------------------------------------------
// Speed Command Mapping
// ---------------------------------------------------------------------------
// Speed commands from the Pi are -100 to +100 (percentage of max).
// These are mapped to a target ticks-per-interval for the PID controller.
// This scaling factor converts speed percentage to encoder ticks per PID
// interval. It depends on motor RPM, gear ratio, and encoder resolution.
//
// TT motors with 20-slot encoder and ~1:48 gear ratio give ~960 edges per
// wheel revolution (quadrature). At full speed (~200 RPM output shaft):
//   960 ticks/rev * 200 RPM / 60 sec = 3200 ticks/sec
//   At 50 Hz PID: 3200 / 50 = 64 ticks per interval at full speed
//
// So speed=100 maps to ~64 ticks/interval. This is approximate and will
// need tuning with real hardware.
#define SPEED_TO_TICKS_SCALE 0.64f  // speed * scale = target ticks/interval
                                     // 100 * 0.64 = 64 ticks/interval
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

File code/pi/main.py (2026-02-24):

#!/usr/bin/env python3
"""
EvoBot Main Loop — reference-01

Five-phase execution cycle: SENSE -> THINK -> ACT -> EVALUATE -> LOG

This is the entry point for the EvoBot robot. It loads configuration,
initializes all subsystems, and runs the main decision loop at a
configurable rate (default 10 Hz).

Governed by the Opengates Constitution (SOUL.md).

Usage:
    python3 -u main.py
    python3 -u main.py --config /path/to/robot.yaml
"""

import argparse
import os
import signal
import sys
import time
from pathlib import Path
from typing import Any, Dict, Optional

import yaml

from evolution import CycleScore, Evaluator
from inference import InferenceEngine
from logger import Logger
from motors import MotorController
from safety import SafetyMonitor
from sensors import SensorHub, SensorState


# ---------- Startup banner ----------

BANNER = r"""
    ______           ____        __
   / ____/  ______  / __ )____  / /_
  / __/ | / / __ \/ __  / __ \/ __/
 / /___| / / /_/ / /_/ / /_/ / /_
/_____/___/\____/_____/\____/\__/

  reference-01  |  Opengates Constitution
  Local-First   |  Self-Evolving
"""


def load_yaml(path: str) -> dict:
    """
    Load a YAML config file.

    Args:
        path: Absolute or relative path to YAML file.

    Returns:
        Parsed dict. Returns empty dict on error.
    """
    try:
        with open(path, "r") as f:
            data = yaml.safe_load(f)
            return data if isinstance(data, dict) else {}
    except Exception as e:
        print(f"[ERROR] Failed to load {path}: {e}", file=sys.stderr)
        return {}


def find_config_dir() -> Path:
    """
    Locate the configs/ directory.

    Searches relative to this script's location, then common deployment paths.

    Returns:
        Path to configs/ directory.
    """
    script_dir = Path(__file__).resolve().parent
    candidates = [
        script_dir / "configs",
        script_dir.parent / "configs",
        Path.home() / "evobot" / "configs",
    ]
    for candidate in candidates:
        if candidate.is_dir():
            return candidate

    # Fallback: use script directory
    return script_dir / "configs"


class EvoBot:
    """
    Main robot controller.

    Manages the five-phase execution loop and coordinates all subsystems.
    Handles graceful startup, shutdown, and error recovery.
    """

    def __init__(self, robot_config: dict, inference_config: dict) -> None:
        """
        Initialize EvoBot from parsed config dicts.

        Args:
            robot_config: Parsed robot.yaml
            inference_config: Parsed inference.yaml
        """
        self._robot_config = robot_config
        self._inference_config = inference_config
        self._running = False
        self._shutdown_requested = False

        # Extract config sections
        self._loop_config = robot_config.get("loop", {})
        self._serial_config = robot_config.get("serial", {})
        # Merge motor config into serial config so MotorController has access
        self._serial_config["motors"] = robot_config.get("motors", {})
        self._sensor_config = robot_config.get("sensors", {})
        self._safety_config = robot_config.get("safety", {})
        self._evolution_config = robot_config.get("evolution", {})
        self._logging_config = robot_config.get("logging", {})

        # Loop timing
        self._target_hz = self._loop_config.get("target_hz", 10)
        self._cycle_period = 1.0 / self._target_hz
        self._heartbeat_interval_s = self._loop_config.get("heartbeat_interval_ms", 250) / 1000.0

        # Initialize subsystems (order matters)
        self._logger = Logger(self._logging_config)
        self._motors = MotorController(self._serial_config, self._logger)
        self._sensors = SensorHub(self._sensor_config, self._logger)
        self._safety = SafetyMonitor(self._safety_config, self._logger, self._motors)
        self._inference = InferenceEngine(self._inference_config, self._logger)
        self._evaluator = Evaluator(self._evolution_config, self._logger)

        # Wire safety module to motors for e_stop capability
        self._safety.set_motors(self._motors)

        # Cycle state
        self._cycle_count = 0
        self._last_heartbeat_time = 0.0
        self._last_sensor_state: Optional[SensorState] = None
        self._last_action: Dict[str, Any] = {"type": "stop", "left": 0, "right": 0}

    def startup(self) -> bool:
        """
        Run the startup sequence.

        1. Print banner
        2. Log session start
        3. Initialize serial to ESP32
        4. Initialize sensors
        5. Run self-test
        6. Report ready status

        Returns:
            True if startup succeeded, False if critical failure.
        """
        # Print banner
        robot_name = self._robot_config.get("robot", {}).get("name", "evobot")
        robot_version = self._robot_config.get("robot", {}).get("version", "0.0.0")
        print(BANNER, file=sys.stderr)
        print(f"  Robot: {robot_name} v{robot_version}", file=sys.stderr)
        print(f"  Loop rate: {self._target_hz} Hz", file=sys.stderr)
        print(f"  Serial: {self._serial_config.get('port', 'N/A')} "
              f"@ {self._serial_config.get('baud', 'N/A')}", file=sys.stderr)
        print(f"  Log session: {self._logger.get_session_path()}", file=sys.stderr)
        print("", file=sys.stderr)

        self._logger.log(
            "INFO", "main",
            f"EvoBot {robot_name} v{robot_version} starting",
            {"config": {
                "target_hz": self._target_hz,
                "serial_port": self._serial_config.get("port"),
                "safety_emergency_cm": self._safety_config.get("emergency_stop_distance_cm"),
            }},
        )

        # Initialize serial connection to ESP32
        self._logger.log("INFO", "main", "Connecting to ESP32 motor controller...")
        serial_ok = self._motors.connect()
        if not serial_ok:
            self._logger.log(
                "WARN", "main",
                "ESP32 connection failed — running without motor control",
            )
            # Non-fatal: robot can still sense and think without motors

        # Initialize sensors
        self._logger.log("INFO", "main", "Initializing sensors...")
        sensor_results = self._sensors.init()

        # Run sensor self-test
        self._logger.log("INFO", "main", "Running sensor self-test...")
        test_results = self._sensors.self_test()
        self._logger.log(
            "INFO", "main",
            f"Self-test complete: {test_results}",
            test_results,
        )

        # Log available inference backends
        backends = self._inference.get_available_backends()
        self._logger.log(
            "INFO", "main",
            f"Inference backends available: {backends}",
        )

        self._logger.log("INFO", "main", "Startup complete — entering main loop")
        return True
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

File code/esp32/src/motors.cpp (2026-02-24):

// =============================================================================
// EvoBot reference-01 — Motor Driver Implementation
// =============================================================================
// L293D truth table (per WIRING.md Section 8.4):
//   IN1=HIGH, IN2=LOW  → Forward
//   IN1=LOW,  IN2=HIGH → Reverse
//   IN1=LOW,  IN2=LOW  → Coast (free spin)
//   IN1=HIGH, IN2=HIGH → Brake (short circuit windings)
//
// We use coast (LOW/LOW) for the stopped state. This lets the robot roll
// to a gentle stop rather than locking the wheels.
// =============================================================================

#include "motors.h"
#include "config.h"

Motors::Motors()
    : _leftSpeed(0)
    , _rightSpeed(0)
    , _leftPWM(0)
    , _rightPWM(0)
    , _leftDir(0)
    , _rightDir(0)
{
}

void Motors::init() {
    // Configure direction pins as outputs
    pinMode(MOTOR_A_IN1, OUTPUT);
    pinMode(MOTOR_A_IN2, OUTPUT);
    pinMode(MOTOR_B_IN3, OUTPUT);
    pinMode(MOTOR_B_IN4, OUTPUT);

    // Configure PWM channels using ESP32 LEDC peripheral
    // ledcSetup(channel, frequency, resolution_bits)
    ledcSetup(PWM_CHANNEL_A, PWM_FREQ, PWM_RESOLUTION);
    ledcSetup(PWM_CHANNEL_B, PWM_FREQ, PWM_RESOLUTION);

    // Attach PWM channels to enable pins
    ledcAttachPin(MOTOR_A_ENA, PWM_CHANNEL_A);
    ledcAttachPin(MOTOR_B_ENB, PWM_CHANNEL_B);

    // Start with motors off — Constitution Article 14: fail-safe default
    eStop();
}

void Motors::setSpeed(int leftSpeed, int rightSpeed) {
    // Clamp to valid range
    leftSpeed = constrain(leftSpeed, -SPEED_MAX, SPEED_MAX);
    rightSpeed = constrain(rightSpeed, -SPEED_MAX, SPEED_MAX);

    _leftSpeed = leftSpeed;
    _rightSpeed = rightSpeed;

    // Determine direction and PWM for each motor
    int leftDir = 0;
    int rightDir = 0;

    if (leftSpeed > 0) leftDir = 1;
    else if (leftSpeed < 0) leftDir = -1;

    if (rightSpeed > 0) rightDir = 1;
    else if (rightSpeed < 0) rightDir = -1;

    int leftPWM = speedToPWM(abs(leftSpeed));
    int rightPWM = speedToPWM(abs(rightSpeed));

    _leftDir = leftDir;
    _rightDir = rightDir;
    _leftPWM = leftPWM;
    _rightPWM = rightPWM;

    applyMotorA(leftPWM, leftDir);
    applyMotorB(rightPWM, rightDir);
}

void Motors::setLeftPWM(int pwm, int direction) {
    pwm = constrain(pwm, 0, 255);
    _leftPWM = pwm;
    _leftDir = direction;
    applyMotorA(pwm, direction);
}

void Motors::setRightPWM(int pwm, int direction) {
    pwm = constrain(pwm, 0, 255);
    _rightPWM = pwm;
    _rightDir = direction;
    applyMotorB(pwm, direction);
}

void Motors::stop() {
    // Controlled stop: ramp down from current PWM to zero.
    // This prevents abrupt mechanical shock and reduces wheel skid.
    int stepsLeft = _leftPWM;
    int stepsRight = _rightPWM;
    int totalSteps = (STOP_RAMP_MS / STOP_RAMP_STEP_MS);

    if (totalSteps <= 0) totalSteps = 1;

    float leftDecrement = (float)stepsLeft / totalSteps;
    float rightDecrement = (float)stepsRight / totalSteps;

    float currentLeft = (float)_leftPWM;
    float currentRight = (float)_rightPWM;

    for (int i = 0; i < totalSteps; i++) {
        currentLeft -= leftDecrement;
        currentRight -= rightDecrement;

        if (currentLeft < 0) currentLeft = 0;
        if (currentRight < 0) currentRight = 0;

        applyMotorA((int)currentLeft, _leftDir);
        applyMotorB((int)currentRight, _rightDir);

        delay(STOP_RAMP_STEP_MS);
    }

    // Ensure we end at exactly zero
    eStop();
}

void Motors::eStop() {
    // IMMEDIATE stop. No ramp. No delay. Constitution Article 14.
    // Set PWM to zero and direction pins to coast (LOW/LOW).
    ledcWrite(PWM_CHANNEL_A, 0);
    ledcWrite(PWM_CHANNEL_B, 0);
    digitalWrite(MOTOR_A_IN1, LOW);
    digitalWrite(MOTOR_A_IN2, LOW);
    digitalWrite(MOTOR_B_IN3, LOW);
    digitalWrite(MOTOR_B_IN4, LOW);

    _leftSpeed = 0;
    _rightSpeed = 0;
    _leftPWM = 0;
    _rightPWM = 0;
    _leftDir = 0;
    _rightDir = 0;
}

// ---------------------------------------------------------------------------
// Private: Apply direction and PWM to Motor A (Left)
// ---------------------------------------------------------------------------
void Motors::applyMotorA(int pwm, int direction) {
    if (direction > 0) {
        // Forward: IN1=HIGH, IN2=LOW
        digitalWrite(MOTOR_A_IN1, HIGH);
        digitalWrite(MOTOR_A_IN2, LOW);
    } else if (direction < 0) {
        // Reverse: IN1=LOW, IN2=HIGH
        digitalWrite(MOTOR_A_IN1, LOW);
        digitalWrite(MOTOR_A_IN2, HIGH);
    } else {
        // Stop: coast (IN1=LOW, IN2=LOW)
        digitalWrite(MOTOR_A_IN1, LOW);
        digitalWrite(MOTOR_A_IN2, LOW);
        pwm = 0;
    }
    ledcWrite(PWM_CHANNEL_A, pwm);
}
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

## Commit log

2026-02-24 Initial commit: EvoBot project foundation
    Recursive self-evolving robot on Raspberry Pi 3. Project structure,
    MIT license, README, contributing guidelines, and setup documentation.
    Pi is live at 192.168.1.51 with SSH key auth.
2026-02-24 Add design philosophy, constitution, and hardware inventory template
    Local-first principle: default to on-device/LAN computation, cloud only
    when local can't deliver 90-95% quality, always with abstracted interfaces
    for future local migration.
    Constitutional governance via Project Opengates SOUL.md — safety hierarchy,
    irreversibility doctrine, fail-safe defaults, authorization levels for
    physical actions.
    Hardware inventory template ready for initial parts cataloguing.
2026-02-24 Add hardware inventory, architecture vision, and shopping list
    Full parts catalogue from shop inventory: motors (BLDC, stepper, servo, DC),
    20+ compute boards, sensors, drivers, fabrication tools. Architecture vision
    defines mid-size parametric platform with distributed compute (Pi brain +
    MCU co-processors), local-first inference stack, and 6-phase evolution
    roadmap through to SO-101 arm integration.
    Shopping list identifies ~$50-90 in parts to unblock v1 build.
2026-02-24 Add v1 BOM ($0 build), budget/reward system, procurement philosophy
    v1 builds entirely from shop stock: TT motors, Arduino motor shield,
    2S battery, ESP32 co-processor, ultrasonic + IMU + webcam sensors,
    laser-cut wood chassis. Zero purchases required.
    Reward program: success unlocks spending ($0→$50→$150→...→$1000 cap).
    Budget is human-controlled parameter. Claude recommends, Scott approves.
2026-02-24 Add system topology documentation
    Three-layer architecture: WSL (development via Claude Code) → Pi 3
    (robot brain, lean Python, API calls for inference) → ESP32 (real-time
    motor control, safety watchdog).
    Claude Code stays on workstation. Robot gets direct API access to Ollama
    (local-first) and Claude API (complex reasoning fallback). Graceful
    degradation when offline.
2026-02-24 Restructure: separate platform from build-specific content
    EvoBot is now a PLATFORM (software, philosophy, constitution) with
    BUILDS (specific hardware configurations). Build-specific files
    (BOM, budget, topology, inventory, shopping list) move into
    builds/reference-01/. Platform-level docs remain in docs/.
    This lets others create their own builds (different motors, boards,
    inference backends) without conflicting with reference-01's choices.
    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
2026-02-24 Add chassis, wiring, and software architecture for reference-01
    CHASSIS (628 lines): Parametric 2-deck design, 250x200mm laser-cut wood,
    all dimensions as named variables for scaling. TT motor mounts, Pi/ESP32
    placement, 3D printed parts list, hand-cutting alternative for
    accessibility. Weight budget ~500-550g within TT motor capability.
    WIRING (1242 lines): Complete pin assignments for Pi 3B (40-pin header)
    and ESP32. Full power distribution from 2S battery through kill switch.
    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
2026-02-24 Add CAD files, Pi software, and ESP32 firmware — build-ready
    CAD (15 files):
    - 3x DXF for laser cutting: bottom_deck, top_deck, all_parts (250x200mm
    parametric plates with motor mounts, standoff holes, sensor slots)
    - 5x STL for 3D printing: motor_mount(2x), ball_caster, standoff(4x),
    sensor_bracket(2x), webcam_mount
    - 5x OpenSCAD source for clean manifold re-export
    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
    [all_parts.dxf, ball_caster.scad, ball_caster.stl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]
2026-02-25 Fix DXF geometry: use LWPOLYLINE with bulge for laser-ready closed paths
    Rewrote generate_dxf.py to use continuous LWPOLYLINE entities with bulge
    values instead of disconnected LINE + ARC entities. Corners are now true
    closed paths that laser software will trace correctly. Repositioned sensor
    cutouts to avoid edge overlap. Added PNG preview rendering for visual
    verification before cutting (Constitution Art. 4 — no ctrl+Z on a laser).
    [all_parts.dxf, bottom_deck.dxf, top_deck.dxf]
2026-03-03 Redesign sensor bracket, add build photos, update project status
    Sensor bracket rewritten as vertical L-bracket with channel rails:
    - Base plate with real M3 through-holes (new box_with_holes_mesh helper)
    - Back wall + two horizontal rails for slide-in HC-SR04 PCB retention
    - All axis-aligned geometry — 0 non-manifold edges
    - Top deck DXF updated with 4x bracket bolt holes
    Build progress: bottom deck laser cut, motor mounts printing.
    [all_parts.dxf, ball_caster.scad, ball_caster.stl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]
